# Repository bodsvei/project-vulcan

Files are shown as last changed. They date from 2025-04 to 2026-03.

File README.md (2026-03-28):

# Project VULCAN

vulcan

A humanoid robot facial structure that can interact with humans — tracking faces, expressing emotions, hearing and speaking.

---

## Features

- **Eyes** — Independent 2-axis eyeball motion, eyelids, and gaze tracking via embedded cameras
- **Mouth** — Lip movement synced with speech and emotional expressions
- **Eyebrows** — Up/down motion to complement expressions
- **Neck** — 2-axis motion (horizontal 360° + vertical tilt)
- **Hearing & Speech** — Microphone array for sound localisation, speech recognition, and TTS output
- **Vision** — Face detection, gaze estimation, emotion recognition (FER), hand-wave detection
- **LLM Integration** — RAG-augmented responses via GPT

---

## Subsystems

### Mechanical
- [Eye, eyelid & eyebrow subsystem](https://www.youtube.com/watch?v=uqxhR49N3ws) — asymmetric eyeball motion with cameras, blinking, and brow movement
- [Mouth subsystem](https://www.youtube.com/watch?v=Ke2lJfY4haM) — lip articulation for speech and emotion
- [Neck subsystem](https://www.youtube.com/watch?v=GJRW8hP-Jcs) — full pan and tilt

### Software
- **`software/vision/`** — face detection, gaze estimation (`t_gaze.py`), emotion recognition (`m_model.py`, `m_expression.py`), hand-wave detection
- **`software/speech/`** — speech-to-text, TTS, voice selection
- **`software/llm/`** — GPT interface and RAG pipeline for context-aware responses
- **`software/core/`** — main driver (`vulcan.py`, `vulcan2.py`) coordinating all subsystems

### Electronics
- Servo PCB (ESP32 & Mega variants) — custom KiCad boards in `electronics/pcb/`
- ESP32-CAM firmware — `electronics/firmware/camera_esp/`
- Arduino servo firmware — `electronics/firmware/serial_arduino/`

---

## Repository Structure

```
project-vulcan/
├── docs/                   # Install guides (CUDA, OpenCV, dlib), diagrams
├── software/
│   ├── core/               # Main entry points
│   ├── vision/             # CV modules
│   ├── speech/             # STT / TTS
│   ├── llm/                # GPT + RAG pipeline
│   │   └── rag/
│   ├── data/               # Knowledge base files for RAG
│   ├── utils/              # Shared helpers
│   ├── tools/              # Diagnostic scripts (check mic, list cameras)
│   ├── experiments/        # Prototypes and WIP scripts
│   ├── models/             # Model weights (gitignored — see models/README.md)
│   ├── archive/            # Deprecated code
│   └── requirements.txt
├── electronics/
│   ├── pcb/                # KiCad projects
│   ├── firmware/           # Arduino / ESP32 sketches
│   └── scripts/            # Python hardware-communication scripts
└── mechanical/             # CAD files (SolidWorks, Fusion, Blender, STL)
    ├── Eye_subsystem/
    ├── Mouth_Subsystem/
    ├── Head Structure/
    ├── Neck Base/
    └── base_holder/
```

> **Model weights** are not tracked in git — see [`software/models/README.md`](software/models/README.md) for download links.  
> **Install guides** for CUDA, OpenCV, and dlib are in [`docs/`](docs/).

---

## Getting Started

```bash
# Install Python dependencies
pip install -r software/requirements.txt

# Download model weights (see software/models/README.md), then run
python software/core/vulcan2.py
```

---

## Built With

- [Python](https://www.python.org/)
- [OpenCV](https://opencv.org/)
- [dlib](http://dlib.net/)
- [LangChain](https://www.langchain.com/) / [OpenAI](https://openai.com/)
- [KiCad](https://www.kicad.org/)
- [ROS](https://www.ros.org/)

## Limitations

- The robot covers only the structure above the neck — no full-body mobility.

## Papa

- [Parth Shah](https://github.com/Parth-Shah-Tool-Kit)
- [Ritwik Sharma](https://github.com/Maker-Rat)

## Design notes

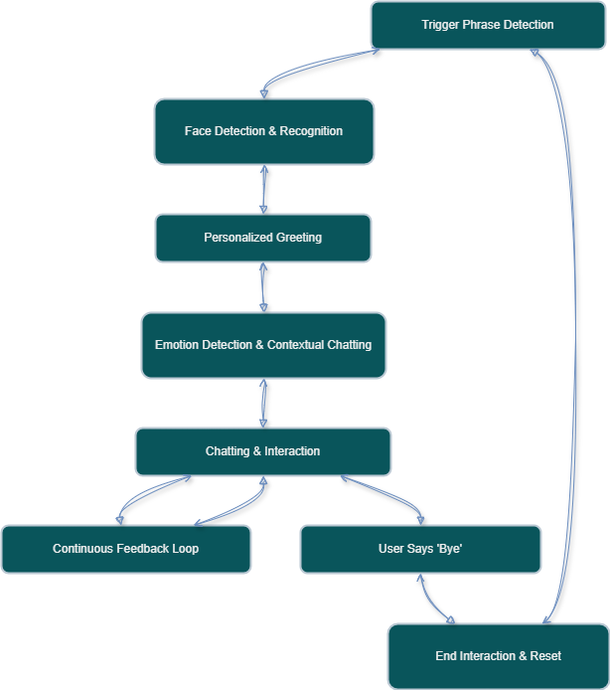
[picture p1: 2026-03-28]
docs/workflow.png

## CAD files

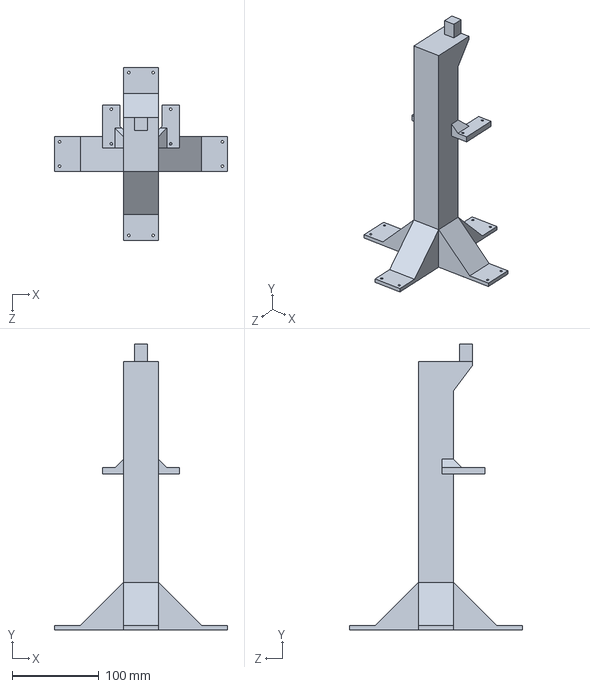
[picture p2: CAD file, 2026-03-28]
mechanical/base_holder/main.SLDPRT
200.0 x 330.0 x 200.0 mm

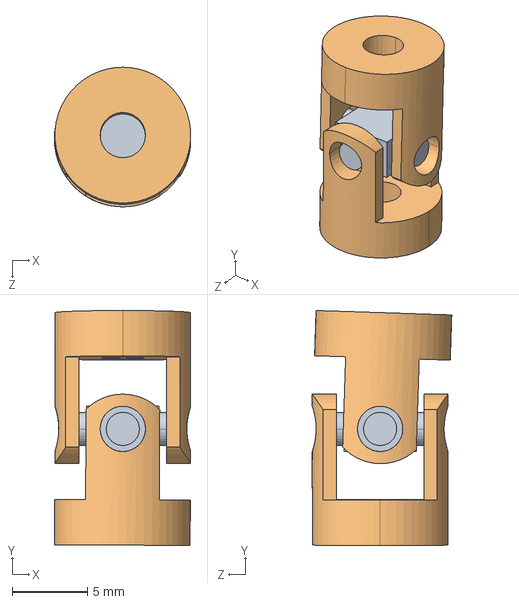
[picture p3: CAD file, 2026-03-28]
mechanical/Eye_subsystem/Solidworks/pla/UV/UV_Final.SLDASM
9.04 x 15.6 x 9.25 mm
UV cross spider[1].step
UV Yoke[1].step x 2

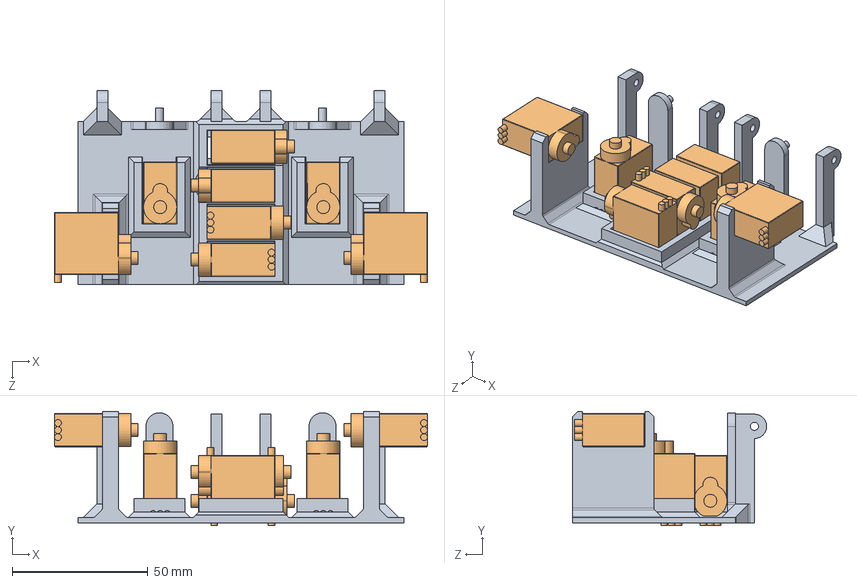
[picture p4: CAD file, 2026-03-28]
mechanical/Eye_subsystem/Solidworks/refrence/Eye Base Plate and Eyes/EyeAssembly.SLDASM
137.2 x 42.0 x 71.5 mm
BASE_v1_complete
servofinal x 8

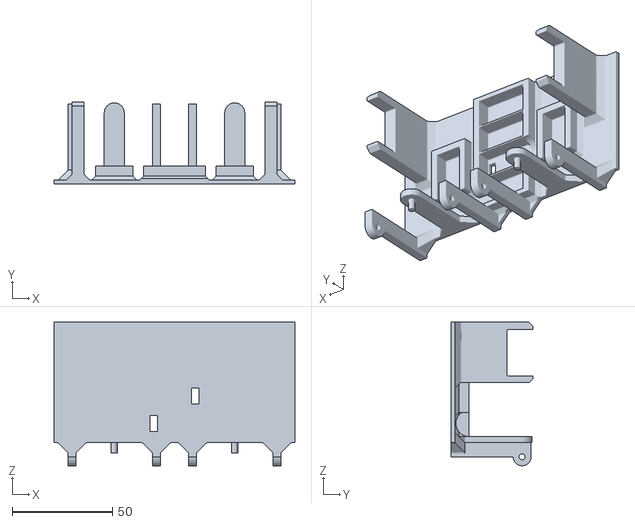
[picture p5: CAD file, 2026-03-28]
mechanical/Eye_subsystem/Solidworks/refrence/Eye Base Plate and Eyes/BASE_v1_complete.STL
120.0 x 41.0 x 71.5

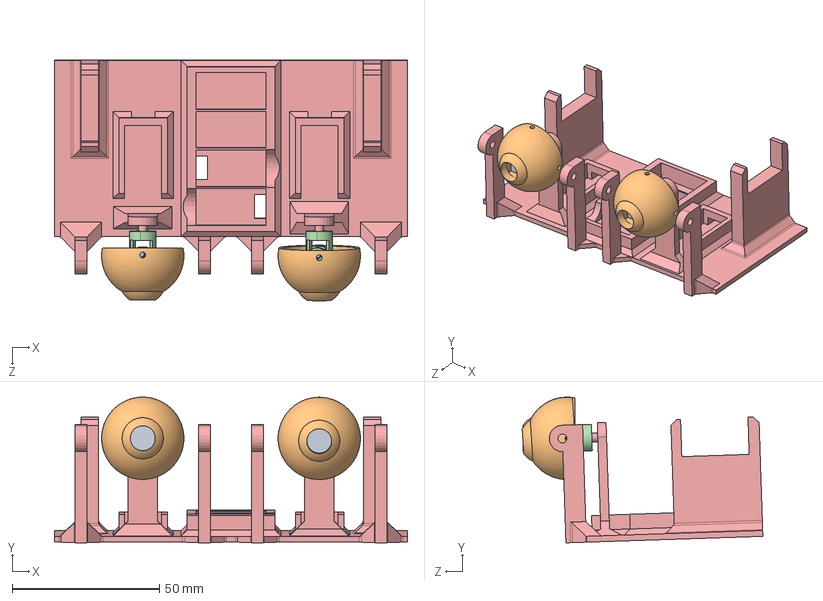
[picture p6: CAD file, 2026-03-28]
mechanical/Eye_subsystem/Solidworks/pla/EyeAssemblyFinal_StepppFile.SLDASM
120.0 x 49.5 x 81.9 mm
UVHOLDERSLDPART x 2
eye ball x 2
UV cross spider[1].step x 2
UV Yoke[1].step x 4
BASE_v3_pasha

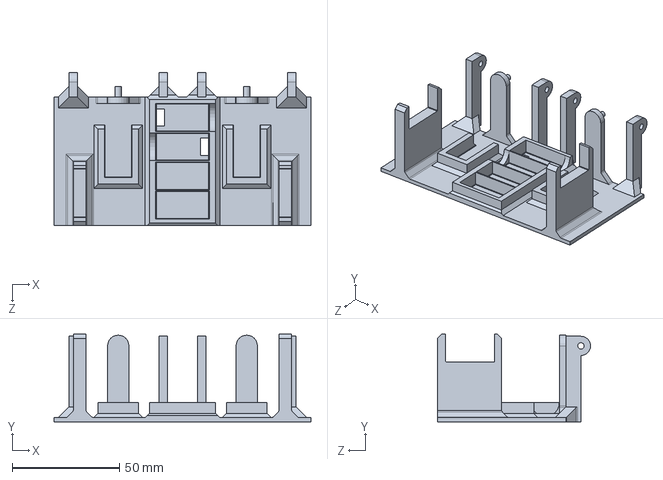
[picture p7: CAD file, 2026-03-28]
mechanical/Eye_subsystem/Solidworks/pla/BASE_v2_complete.SLDPRT
120.0 x 41.0 x 71.5 mm

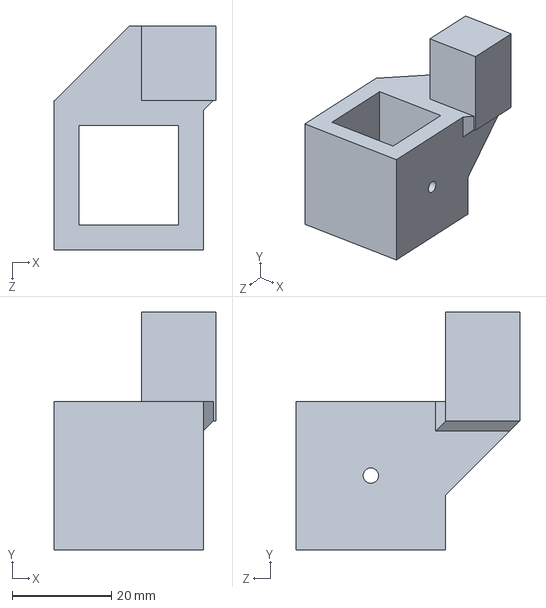
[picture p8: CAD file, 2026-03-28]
mechanical/base_holder/v2/top.SLDPRT
32.6 x 48.0 x 45.1 mm

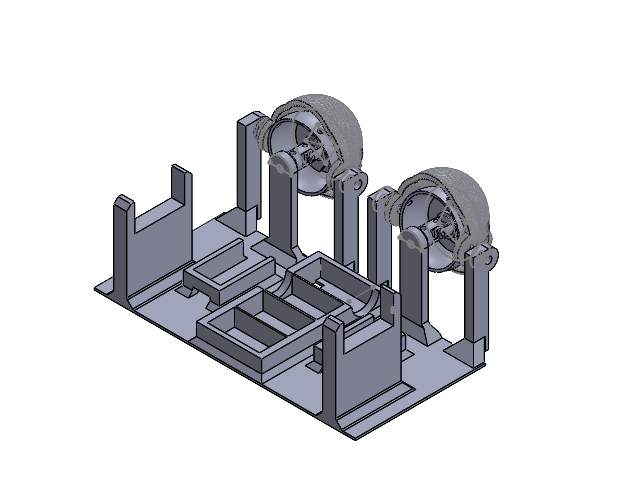
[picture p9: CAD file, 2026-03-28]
mechanical/Eye_subsystem/Solidworks/metal/EyeSubSystem_v5.SLDASM
BASE_v4_metal
Cross metal x 2
UV metal x 4
UVHOLDERSLDPART_v3 x 2
eye ball x 2
lower_eye_lid x 2
Upper Eye Lid x 2

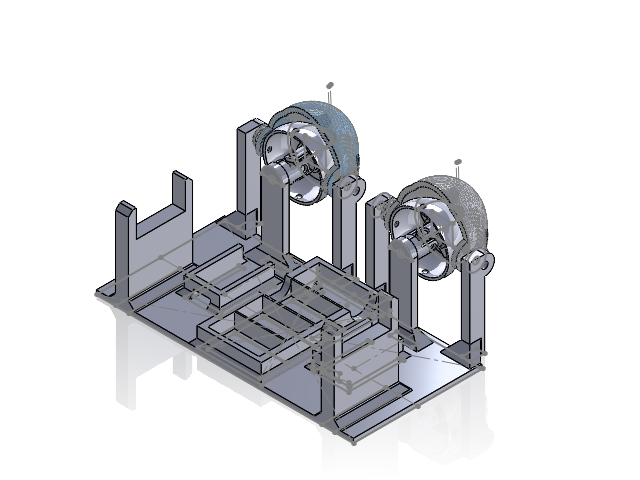
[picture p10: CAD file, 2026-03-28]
mechanical/Eye_subsystem/Solidworks/pla/EyeSubSystem.SLDASM
BASE_v3_pasha
UV cross spider[1].step x 2
UV Yoke[1].step x 4
UVHOLDERSLDPART x 2

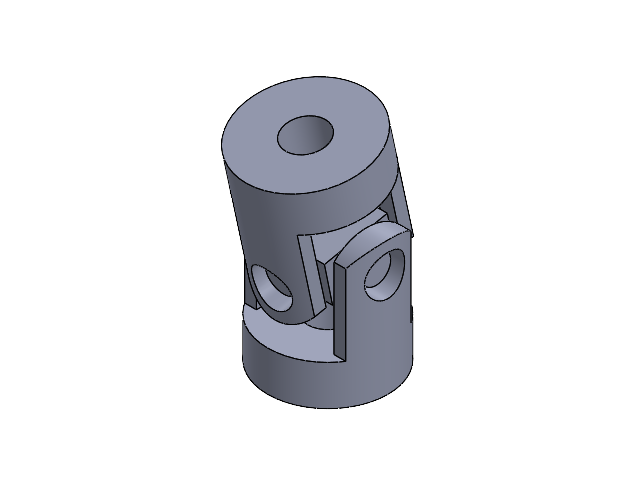
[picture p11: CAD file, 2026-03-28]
mechanical/Eye_subsystem/Solidworks/pla/UV/UV.SLDASM
UV Yoke x 2
UV cross spider

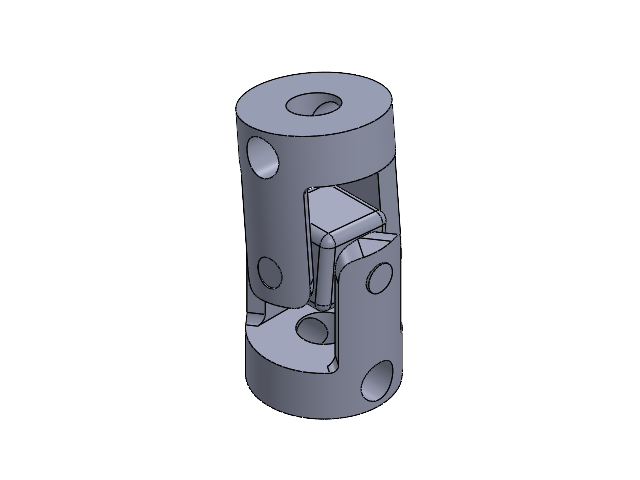
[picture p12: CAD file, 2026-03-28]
mechanical/Eye_subsystem/Solidworks/metal/UV_metal.SLDASM
Cross metal
UV metal x 2

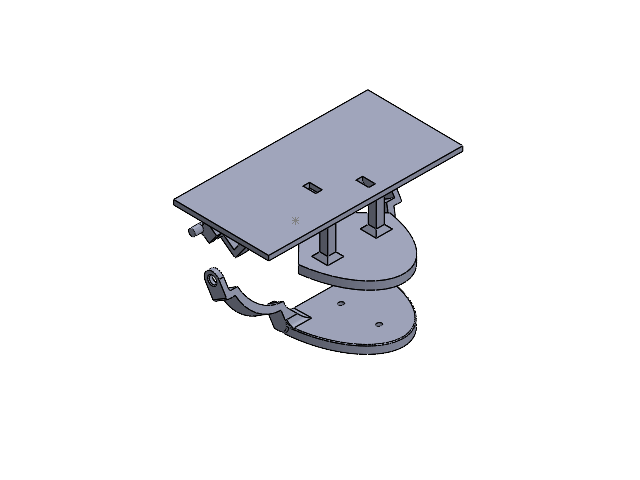
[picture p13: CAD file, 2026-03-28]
mechanical/Mouth_Subsystem/Solidworks/Full_Mechanism/MouthFinished.SLDASM
Lower_Jaw_Plate
Mouth_Base
Cap
servofinal[1] x 2
Slider_DriverServo
Sliding_servo
Connector

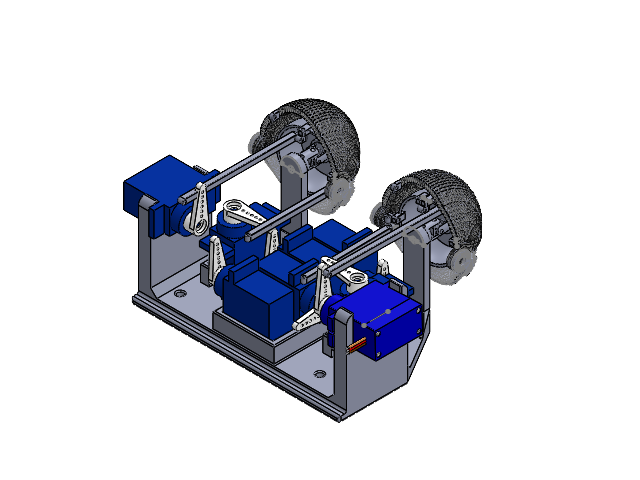
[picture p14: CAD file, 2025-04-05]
mechanical/Eye_subsystem/Solidworks/main/assem.SLDASM
BASE_v8
servofinal[1] x 7
servo_dandi x 8
pusher_rod x 2
pusher_rod_mini x 2
pusher_rod_lr x 2
pusher_rod_mini_lr x 2
Cross metal x 2
UV metal x 4
eye ball_for_pusher_rod x 3
UVHOLDERSLDPART_v3 x 2
Tower+Pro+9g+Micro+Servo+SG90
Upper_eyelid_for_push_rod x 2
Lower_eyelid_for_push_rod x 2

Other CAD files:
mechanical/Eye_subsystem/Solidworks/pla/EyeAssemblyFinal.SLDASM
mechanical/Eye_subsystem/Solidworks/main/UV_metal.SLDASM
mechanical/Eye_subsystem/Solidworks/pla/EyeAssemblyFinal2.SLDASM
mechanical/Eye_subsystem/Solidworks/pla/UV_Final.SLDASM
mechanical/Eye_subsystem/Blender/Eyeball.blend
mechanical/Eye_subsystem/Fusion/eyeball_blender_to_fusion.f3d
mechanical/Eye_subsystem/Fusion/eyeball_dimensionally_inorrect.f3d
mechanical/Eye_subsystem/Solidworks/main/BASE_v7.SLDPRT
mechanical/Eye_subsystem/Solidworks/main/BASE_v8.SLDPRT
mechanical/Eye_subsystem/Solidworks/main/Cross metal.SLDPRT
mechanical/Eye_subsystem/Solidworks/main/Lower_eyelid_for_push_rod.SLDPRT
mechanical/Eye_subsystem/Solidworks/main/Tower+Pro+9g+Micro+Servo+SG90.SLDPRT
mechanical/Eye_subsystem/Solidworks/main/UV metal.SLDPRT
mechanical/Eye_subsystem/Solidworks/main/UVHOLDERSLDPART_v3.SLDPRT
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

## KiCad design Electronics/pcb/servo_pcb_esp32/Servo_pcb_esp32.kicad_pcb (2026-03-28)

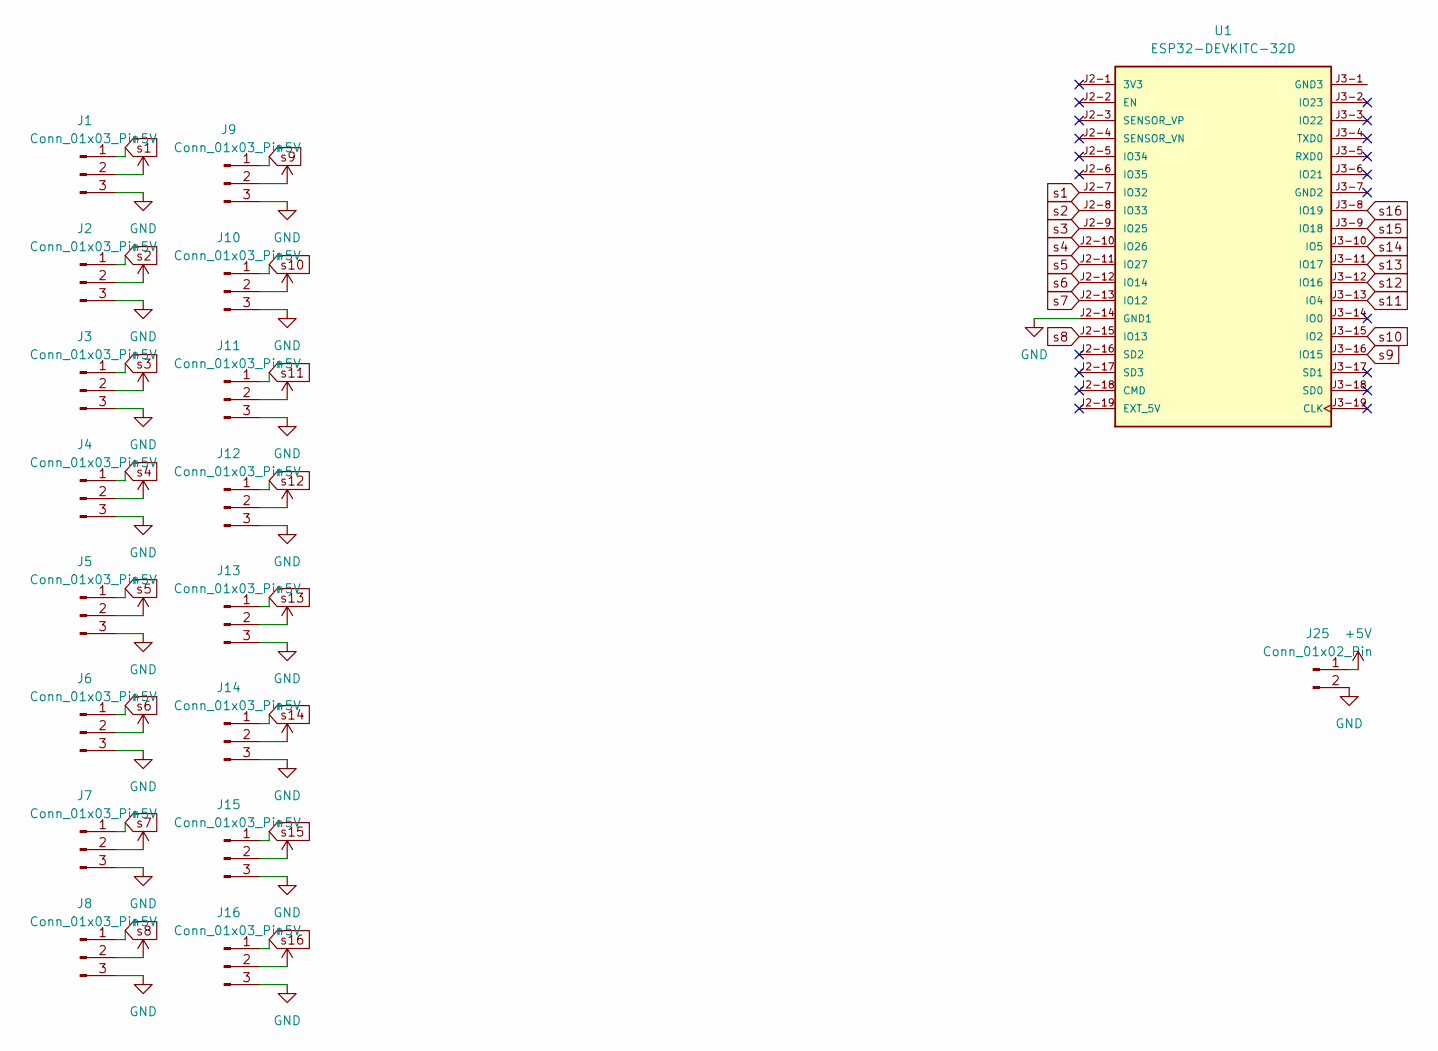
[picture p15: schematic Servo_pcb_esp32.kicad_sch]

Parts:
J1, J2, J3, J4, J5, J6, J7, J8, J9, J10, J11, J12, J13, J14, J15, J16: Conn_01x03_Pin; PinHeader_1x03_P2.54mm_Vertical
J25: Conn_01x02_Pin; AMASS_XT60-M_1x02_P7.20mm_Vertical
U1: ESP32-DEVKITC-32D; MODULE_ESP32-DEVKITC-32D; PARTREV V4

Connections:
+5V: J1.2, J2.2, J3.2, J4.2, J5.2, J6.2, J7.2, J8.2, J9.2, J10.2, J11.2, J12.2, J13.2, J14.2, J15.2, J16.2, J25.1
GND: J1.3, J2.3, J3.3, J4.3, J5.3, J6.3, J7.3, J8.3, J9.3, J10.3, J11.3, J12.3, J13.3, J14.3, J15.3, J16.3, J25.2, U1.J2-14 (GND1)
s1: J1.1, U1.J2-7 (IO32)
s2: J2.1, U1.J2-8 (IO33)
s3: J3.1, U1.J2-9 (IO25)
s4: J4.1, U1.J2-10 (IO26)
s5: J5.1, U1.J2-11 (IO27)
s6: J6.1, U1.J2-12 (IO14)
s7: J7.1, U1.J2-13 (IO12)
s8: J8.1, U1.J2-15 (IO13)
s9: J9.1, U1.J3-16 (IO15)
s10: J10.1, U1.J3-15 (IO2)
s11: J11.1, U1.J3-13 (IO4)
s12: J12.1, U1.J3-12 (IO16)
s13: J13.1, U1.J3-11 (IO17)
s14: J14.1, U1.J3-10 (IO5)
s15: J15.1, U1.J3-9 (IO18)
s16: J16.1, U1.J3-8 (IO19)

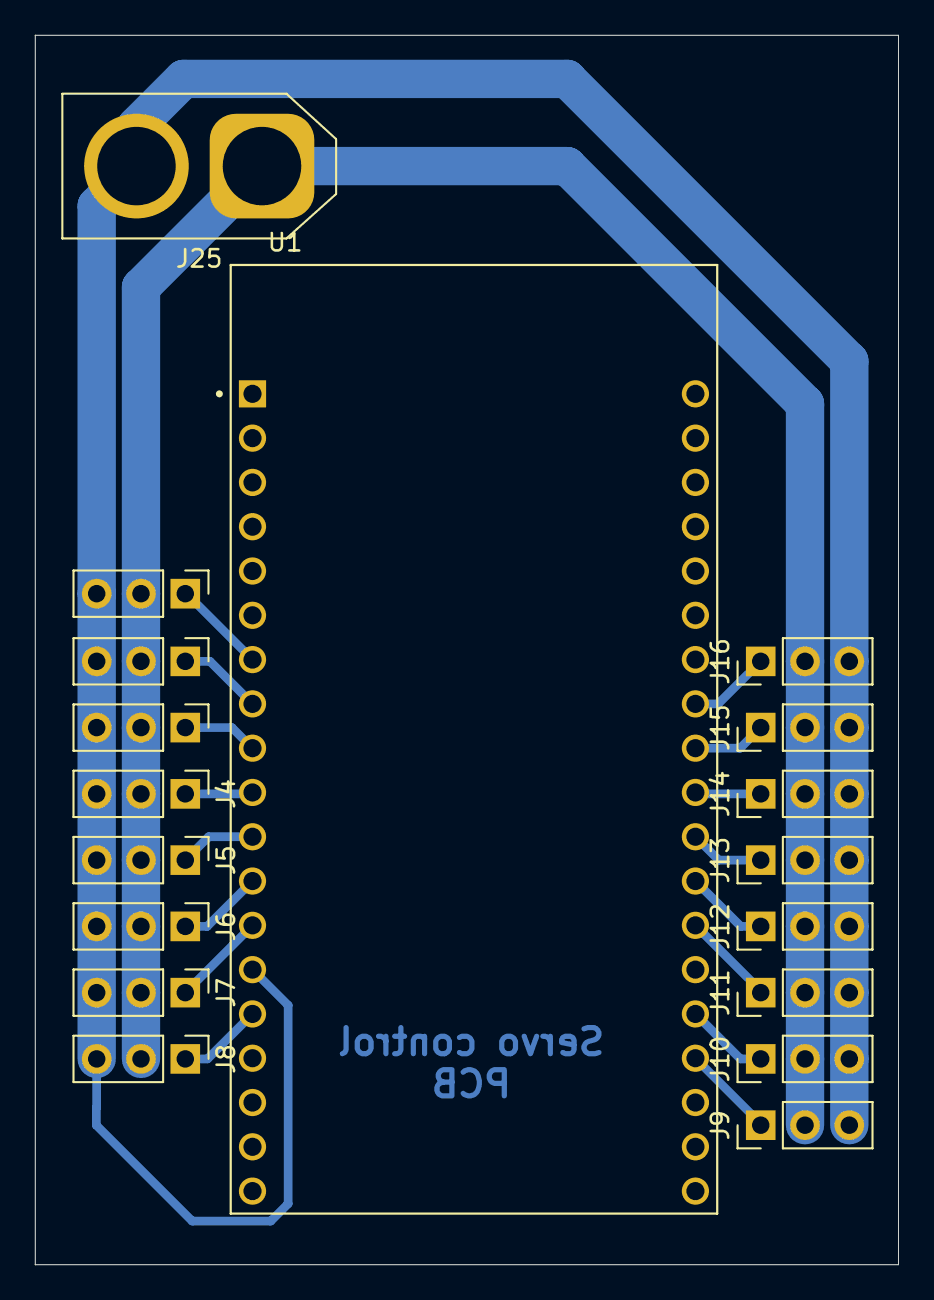
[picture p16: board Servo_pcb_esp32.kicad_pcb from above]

Board: 2 copper layers, 49.5 x 70.5 mm, 18 parts (0 on the bottom side), 18 nets.

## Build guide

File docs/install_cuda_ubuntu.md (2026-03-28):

How to install gpu support for linux. (i am using ubuntu 22, python 3.10, rtx 3050 4gb, intel i7 12g)

1. Take backup
2. Remove any relevant installs:

sudo bash -c "echo 'blacklist nouveau' > /etc/modprobe.d/blacklist-nouveau.conf"
sudo bash -c "echo 'options nouveau modeset=0' >> /etc/modprobe.d/blacklist-nouveau.conf"

sudo apt-get --purge remove "*nvidia*"
sudo apt-get --purge remove "*cuda*"
sudo apt-get --purge remove "*cublas*" "cuda*" "nsight*"
sudo apt-get autoremove
sudo apt-get autoclean

sudo update-initramfs -u

sudo reboot

3. Now install basic nvidia driver

sudo apt-get update
sudo apt-get install nvidia-driver-535 (535 is for rtx 3050 search your releveant one)

4. Fix broken packages: 
sudo apt-get install -f
sudo apt-mark showhold

5. find the cuda version for your gpu (12.2 for mine):
https://developer.nvidia.com/cuda-12-2-0-download-archive
follow the steps for deb(local) > best way

do everthing in the /home/user/ folder

6. Add Env varibles
echo $PATH
echo $LD_LIBRARY_PATH
echo 'export PATH=/usr/local/cuda-12.2/bin${PATH:+:${PATH}}' >> ~/.bashrc
echo 'export LD_LIBRARY_PATH=/usr/local/cuda-12.2/lib64${LD_LIBRARY_PATH:+:${LD_LIBRARY_PATH}}' >> ~/.bashrc

sudo reboot

7. Check if cuda is installed:
source ~/.bashrc
nvcc --version
something like:
nvcc: NVIDIA (R) Cuda compiler driver
Copyright (c) 2005-2023 NVIDIA Corporation
Built on Tue_Jun_13_19:16:58_PDT_2023
Cuda compilation tools, release 12.2, V12.2.91
Build cuda_12.2.r12.2/compiler.32965470_0

should come.

8. find the cudnn version for your cuda from here: (9.2 for mine)
https://docs.nvidia.com/deeplearning/cudnn/latest/reference/support-matrix.html
download cudnn from here:
https://developer.nvidia.com/cudnn-downloads

dpkg -l | grep cudnn
this should show atlest:
ii  cudnn9-cuda-12                                     9.2.0.82-1                                        amd64        NVIDIA cuDNN for CUDA 12

with ii in the start.

sudo reboot for cudnn installation if you get random errors.

sudo apt-get install libcudnn8
sudo apt-get install libcudnn8-dev

incase of package not found,

wget https://developer.download.nvidia.com/compute/cuda/repos/ubuntu2004/x86_64/cuda-ubuntu2004.pin
sudo mv cuda-ubuntu2004.pin /etc/apt/preferences.d/cuda-repository-pin-600
export last_public_key=3bf863cc # SEE NOTE BELOW
sudo apt-key adv --fetch-keys https://developer.download.nvidia.com/compute/cuda/repos/ubuntu2004/x86_64/${last_public_key}.pub
sudo add-apt-repository "deb https://developer.download.nvidia.com/compute/cuda/repos/ubuntu2004/x86_64/ /"
sudo apt-get update
sudo apt-get install libcudnn8
sudo apt-get install libcudnn8-dev

now if libcudnn gets installed, you are done with cudnn installation.

9. Install NVIDIA Video Codec SDK
from https://developer.nvidia.com/video-codec-sdk
refer https://www.youtube.com/watch?v=zap4k6LKnYA

9. Now we build opencv!

pip3 uninstall opencv-python

sudo apt-get update
sudo apt-get install build-essential cmake git libgtk2.0-dev pkg-config libavcodec-dev libavformat-dev libswscale-dev
sudo apt-get install libgstreamer-plugins-base1.0-dev libgstreamer1.0-dev libgl1-mesa-dev libglu1-mesa-dev
sudo apt-get install python3-dev python3-numpy libtbb2 libtbb-dev libjpeg-dev libpng-dev libtiff-dev libdc1394-22-dev

sudo apt-get install libdc1394-dev

git clone https://github.com/opencv/opencv.git
git clone https://github.com/opencv/opencv_contrib.git
cd opencv_contrib
git checkout <opencv_version>  # Replace <opencv_version> with the version you want to build (e.g., 4.5.5)
cd ..

cd opencv
git checkout <opencv_version>  # Replace <opencv_version> with the version you want to build (e.g., 4.5.5)
mkdir build
cd build

# Configure with CUDA and cuDNN support
cmake .. -DOPENCV_EXTRA_MODULES_PATH=../opencv_contrib/modules \
         -DWITH_CUDA=ON \
         -DCUDA_ARCH_BIN=8.6 \
         -DCUDA_FAST_MATH=ON \
         -DCUDNN_VERSION=9.6.0 \
         -DCUDNN_INCLUDE_DIR=/usr/include \
         -DCUDNN_LIBRARY=/usr/lib/libcudnn.so.9.6.0 \
         -DBUILD_opencv_python2=OFF \
         -DBUILD_opencv_python3=ON \
         -DPYTHON_DEFAULT_EXECUTABLE=/usr/bin/python3 \
         -DWITH_GSTREAMER=ON \
         -DWITH_LIBV4L=ON \
         -DENABLE_FAST_MATH=ON \
         -DCMAKE_BUILD_TYPE=RELEASE \
         -DBUILD_EXAMPLES=OFF \
         -DBUILD_TESTS=OFF \
         -DBUILD_PERF_TESTS=OFF

# Adjust options as per your specific requirements

make -j10 (replace 10 with no of your cpu cores) (this is for building)
sudo make install
sudo ldconfig

if you mess up, uninstall cudnn and do again.

if you get this error: 
"CMake Error at modules/dnn/CMakeLists.txt:53 (message):
  DNN: CUDA backend requires cuDNN.  Please resolve dependency or disable
  OPENCV_DNN_CUDA=OFF"
  
  It means cudnn install is improper/incomplete/not supported. So delete and install again (best)
  
To test for sucessful build:

python3
import cv2
print(cv2.__version__)
print(cv2.getBuildInformation())
cv2.cuda.getCudaEnabledDeviceCount()

last one should print 1

If you made it so far congratulations! its easy now.

sudo rm -rf ~/opencv
sudo rm -rf ~/opencv_contrib

10. Now we build dlib!

pip3 uninstall dlib

cd
git clone https://github.com/davisking/dlib.git
cd dlib
mkdir build
cd build
cmake .. -DDLIB_USE_CUDA=1 -DUSE_AVX_INSTRUCTIONS=1
cmake --build .
sudo make install
sudo ldconfig
cd ../
python3 setup.py install --set USE_AVX_INSTRUCTIONS=1 --set DLIB_USE_CUDA=1

incase of an error write
python3 setup.py install --set USE_AVX_INSTRUCTIONS=1 --set DLIB_USE_CUDA=1 --user
and retry

test with:
import dlib
print("Dlib version:", dlib.__version__)
print("CUDA support:", dlib.DLIB_USE_CUDA)

sudo rm -rf ~/dlib

11. Now we build tensorflow!

pip3 uninstall tensorflow
python3 -m pip install tensorflow[and-cuda]

to test:
import tensorflow as tf

# Check if TensorFlow can access GPU
print("Num GPUs Available:", len(tf.config.experimental.list_physical_devices('GPU')))

12. Now we build pytorch!

pip3 uninstall torch torchvision torchaudio
rm -rf ~/.cache/torch
pip3 list | grep torch

this should be empty

pip3 install torch torchvision torchaudio -f https://download.pytorch.org/whl/cu12.2/torch_stable.html

this is for cuda 12.2 choose link accordingly

to test:
import torch
print(torch.__version__)
print(torch.cuda.is_available())

if you get "ImportError: libcudnn.so.8: cannot open shared object file: No such file or directory"
while doing import torch
then do:

sudo rm /usr/lib/x86_64-linux-gnu/libcudnn.so.8
sudo ln -s /usr/lib/x86_64-linux-gnu/libcudnn.so.9.2.0 /usr/lib/x86_64-linux-gnu/libcudnn.so.8

/usr/lib/x86_64-linux-gnu is the place where your libcudnn should be present

sudo apt-cache policy libcudnn8
and then install the appropriate version.

If you make it so far, congratulations. Your done!

GG. 
Happy computer vision at good fps.

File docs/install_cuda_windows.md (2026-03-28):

Cuda version: 11.2 download from nvidia website.
download zlib and add .dll to path
CUDNN v 8.1.1.33 download from nvidia website. follow installation instructions from website.
dont forget to add cudnn to path.
check by typing nvcc --version in cmd.

dlib download 19.23 from github
opencv 4.x from github.
opencv_contrib same v from github.

download cmake as a software, not with pip
download visual studio 2019.
install visual studio build tools 2017 and 2019. select c++ tools. make sure tools for cmake is ticked.

now we build dlib.
use cmake to build dlib.

use source code as dlib folder path
where to build as dlib folder path / build. create a build folder by yourself.

Make sure you dont use jionet now onwards.
If you see blank screen, press configure. use visual studio 2017 and set x64 in next blank.
now change DLIB_USE_CUDA to ON or ticked and same for DLIB_LINK_WITH_SQLITE3.

now press configure and if you see "DLIB WILL USE CUDA", congrats, you are almost done (hopefully). Delete older installed versions of dlib with pip or go into site_packages folder and delete it.
Now press generate and close cmake once this is done.
Go to build folder that you create. open cmd there and type "cmake ." . after this do cd.. or go to dlib folder and open cmd. type "python setup.py install"

you can check by closing all python codes and opening a python terminal and writing in shell:

import dlib
dlib.DLIB_USE_CUDA
if you get true, congratulations.

moving to open cv, first uninstall all.
https://www.youtube.com/watch?v=d8Jx6zO1yw0
follow this video step by step.

hope it works.

I have used python 3.7.4, windows 11, nvidia gpu rtx 3050, intel i7 (x64).

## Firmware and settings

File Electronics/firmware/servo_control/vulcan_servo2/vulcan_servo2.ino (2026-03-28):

#include <ESP32Servo.h>

// Define the servo object
Servo Mouth_linear;
Servo Mouth_Rotational;
//Servo myServo3;
//Servo myServo4;
Servo L_lid_D;
Servo L_lid_U;
Servo L_eye_LR;
Servo L_eye_UD;
Servo R_eye_UD;
Servo R_eye_LR;
Servo R_lid_U;
Servo R_lid_D;
//Servo myServo13;
//Servo myServo14;
//Servo myServo15;
//Servo myServo16;

bool blinking = 1;
bool Talk = 0;

hw_timer_t *timer1 = NULL;
hw_timer_t *timer2 = NULL;

int L_eye_H = 87;
int L_eye_V = 97;
int R_eye_H = 125;
int R_eye_V = 80;

int increment = 4;

volatile int angle_2 = 0;
volatile bool increasing2 = true;

volatile int angle3 = 0;
volatile bool increasing3 = true;

int blink_speed = 2;
int talking_speed = 2;
int bl_counter = 0;
int tl_counter = 0;

int randomNumber = random(5, 10);

void IRAM_ATTR onTimer1() 
{
  tl_counter++;
  if(blinking==1)
  {
    if(bl_counter%(randomNumber*1000) == 0)
    {
      L_lid_U.write(70);
      R_lid_U.write(40);
    }
    if(bl_counter%(randomNumber*1000) == 250)
    {
      L_lid_U.write(0);
      R_lid_U.write(135);
      randomNumber = random(3, 7);
      blinking = 0;
    }
    bl_counter++;
  }
  if(Talk==1)
  {
    if(tl_counter% 800 == 0)
    {
      Mouth_Rotational.write(95);
    }
    if(tl_counter%800 == 400)
    {
      Mouth_Rotational.write(85);
    }
  }
}


void setup() {
  Serial.begin(115200);

  Mouth_linear.attach(15);
  Mouth_Rotational.attach(2);
  //  myServo3.attach(4);
  //  myServo4.attach(16);
  L_lid_D.attach(17);
  L_lid_U.attach(5);
  L_eye_LR.attach(18);
  L_eye_UD.attach(19);
  R_eye_UD.attach(32);
  R_eye_LR.attach(33);
  R_lid_U.attach(25);
  R_lid_D.attach(26);
  //  myServo13.attach(27);
  //  myServo14.attach(14);
  //  myServo15.attach(12);
  //  myServo16.attach(13);
  
  L_lid_D.write(85);
  L_lid_U.write(0);
  L_eye_LR.write(87);
  L_eye_UD.write(97);
  R_eye_UD.write(80);
  R_eye_LR.write(125);
  R_lid_U.write(135);
  R_lid_D.write(117);
  Mouth_linear.write(140);
  Mouth_Rotational.write(85);

    // Create a hardware timer
  timer1 = timerBegin(1000000); // Timer 1, prescaler of 80 (1 tick = 1 µs)
  timerAttachInterrupt(timer1, &onTimer1); // Attach interrupt
  timerAlarm(timer1, 1000, true, 0); // Set alarm to 5 seconds (5,000,000 µs)

//  timer2 = timerBegin(1000000); // Timer 2
//  timerAttachInterrupt(timer2, &onTimer2);
//  timerAlarm(timer2, 1000, true, 0); // 300 miliseconds for Servo 2
}

void check_cond()
{
   if (L_eye_V >= 115)
      L_eye_V = 115;
    if (L_eye_V <= 85)
      L_eye_V = 85;
      
    if (L_eye_H >= 115)
      L_eye_H = 115;
    if (L_eye_H <= 60)
      L_eye_H = 60;

    if (R_eye_V >= 100)
      R_eye_V = 100;
    if (R_eye_V <= 65)
      R_eye_V = 65;
      
    if (R_eye_H >= 150)
      R_eye_H = 150; 
    if (R_eye_H <= 95)
      R_eye_H = 95;
}
void loop() {
  unsigned long currentMillis = millis();  // Get the current time

  if (Serial.available() > 0) 
  {
    int receivedValue = 5;
    receivedValue = Serial.parseInt();
    Serial.println(receivedValue);
   
    if (receivedValue == 1)             //Eye left
    {
      L_eye_H += increment;
      R_eye_H += increment;
    } 
    else if (receivedValue == 2)        //Eye right
    {
      L_eye_H -= increment;
      R_eye_H -= increment;
    } 
    else if (receivedValue == 3)        //Eye up 
    {
      L_eye_V += increment;
      R_eye_V -= increment;
    } 
    else if (receivedValue == 4)        //Eye down 
    {
      
      L_eye_V -= increment;
      R_eye_V += increment;
    } 
    else if (receivedValue == 5)        //Centre 
    {
      L_eye_H = 87;
      L_eye_V = 97;
      R_eye_H = 125;
      R_eye_V = 80;
    } 
    else if (receivedValue == 6)        //Left wink
    {  
       blinking = 0;
       for (int angle = 0; angle <= 70; angle++) 
       {
          L_lid_U.write(angle);
          delay(10);
       }
       delay(500);
       L_lid_U.write(0);
       blinking = 1;
    } 
    else if (receivedValue == 7)        //Right wink
    {
      blinking = 0;
      for (int angle = 135; angle >= 40; angle--) 
      {
        R_lid_U.write(angle);
        delay(10);
      }
      delay(500);
      R_lid_U.write(135);
      blinking = 1;
    } 
    else if (receivedValue == 8)      //Talk
    {
      Talk = 1;
    } 
    else if (receivedValue == 9)      //Stop talk
    {
      Talk = 0;
    } 
    else if (receivedValue == 10)     //Yawn
    {
      if(Talk == 0)
      {
         blinking = 0;
        for (int angle = 85; angle <= 115; angle++) 
        {
            R_lid_U.write((int)(-3.167*angle+404.167));
           L_lid_U.write((int)(2.333*angle-198.333));
            Mouth_linear.write((int)(-1.433*angle+261.833));
            Mouth_Rotational.write(angle);
            delay(30);
        }
        delay(800);
        for (int angle = 115; angle >= 85; angle--) 
        {
            Mouth_linear.write((int)(-1.433*angle+261.833));
            Mouth_Rotational.write(angle);
            delay(5);
        }  
        L_lid_U.write(0);
        R_lid_U.write(135);
        blinking = 1;

      }
    } 
    else if (receivedValue == 11)     //Look around
    {
      // for (int angle = 125; angle <= 160; angle++)
      // {
      //   R_eye_LR.write(angle);
      //   L_eye_LR.write(3*angle-325);
      //   delay(30);
      // }
      // for (int angle = 160; angle >= 85; angle--) 
      // {
      //   R_eye_LR.write(angle);
      //   L_eye_LR.write(3*angle-325);
      //   delay(30);
      // }

      // for (int angle = 125; angle <= 150; angle++)
      // {
      //   R_eye_LR.write(angle);
      //   L_eye_LR.write(3*angle-325);
      //   delay(15);
      // }
      // for (int angle = 140; angle >= 85; angle--) 
      // {
      //   R_eye_LR.write(angle);
      //   L_eye_LR.write(3*angle-325);
      //   delay(15);
      // }
      
    } 
    else if (receivedValue == 12) 
    {
      //Eye roll
      /*for (int i = 0; i < steps; i++) 
      {
        // Calculate the angle in radians
        angle = (2 * PI / steps) * i;

        // Calculate x and y using parametric equations
        int x = xc + radius * cos(angle);
        int y = yc + radius * sin(angle);

        // Ensure x and y are within the allowed range
        if (x >= 70 && x <= 105 && y >= 86 && y <= 108) {
            printf("(%d, %d)\n", x, y);
        }
      }*/
    } else if (receivedValue == 13) {
      //Sleep
    } else if (receivedValue == 14) {
      //Squint
    } else if (receivedValue == 15) {
      //Creep eyes
    }
  }
    check_cond();
   
    if(blinking == 0)
    {
      L_lid_D.write(85);
      L_lid_U.write(0);
      R_lid_U.write(135);
      R_lid_D.write(117);
      blinking = 1;
    }
    L_eye_LR.write(L_eye_H);
    L_eye_UD.write(L_eye_V);
    R_eye_UD.write(R_eye_V);
    R_eye_LR.write(R_eye_H);
    
    if(Talk == 0)
    {
      Mouth_linear.write(140);
      Mouth_Rotational.write(85);
    }

}

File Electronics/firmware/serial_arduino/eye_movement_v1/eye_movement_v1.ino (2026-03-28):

#include <Servo.h>

//CW -> towards zero (looking at servo)


Servo eye_left_right;
Servo eye_up_down;

Servo eyelid_up;
Servo myservo3;
Servo myservo4;
// Servo myservo5;
// Servo myservo6;
// Servo myservo7;
Servo eye_other;

int eye_left_right_angle = 90;
int eye_up_down_angle = 90;

int eyelid_up_angle = 30;
int eye_other_angle = 50;

int limit = 20, increment = 5;

int eye_change = 15;




unsigned long previousMillis = 0;     // Store the last time the servo moved
const unsigned long interval = 5000;  // 5 seconds in milliseconds
const unsigned long interval_blink = 100;


void setup() {
  // put your setup code here, to run once:
  Serial.begin(115200);

  eye_left_right.attach(2);
  eye_up_down.attach(3);

  eyelid_up.attach(4);
  //myservo4.attach(5);
  // myservo5.attach(6);
  // myservo6.attach(7);
  // myservo7.attach(8);
  // myservo8.attach(9);

  eye_left_right.write(90);
  eye_up_down.write(90);
  eyelid_up.write(eyelid_up_angle);

  eye_other.attach(5);
  eye_other.write(eye_other_angle);
}

void loop() {

  unsigned long currentMillis = millis();  // Get the current time

  if (Serial.available() > 0) {


    // Serial.println(Serial.parseInt());
    int receivedValue = 5;
    receivedValue = (int)Serial.read();
    Serial.println(receivedValue);


    if (receivedValue == 7) {
      //go left
      eye_left_right_angle += increment;

    } else if (receivedValue == 2) {
      //go right
      eye_left_right_angle -= increment;

    } else if (receivedValue == 1) {
      //go up
      eye_up_down_angle += increment;
    } else if (receivedValue == 3) {
      //go down
      eye_up_down_angle -= increment;
    } else if (receivedValue == 5) {
      //center
    }

    if (eye_left_right_angle >= 90 + limit)
      eye_left_right_angle -= increment;
    if (eye_left_right_angle <= 90 - limit)
      eye_left_right_angle += increment;

    if (eye_up_down_angle >= 90 + limit)
      eye_up_down_angle -= increment;
    if (eye_up_down_angle <= 90 - limit)
      eye_up_down_angle += increment;

    // Serial.println(eye_left_right_angle);
    eye_left_right.write(eye_left_right_angle);
    eye_up_down.write(eye_up_down_angle);
  }



  if (currentMillis - previousMillis >= interval) {
    // It's time to move the servo
    previousMillis = currentMillis;  // Save the last time the servo moved


    eyelid_up.write(eyelid_up_angle - eye_change);
    eye_other.write(eye_other_angle + eye_change);
    // eye_change = -eye_change;
    // delay(interval_blink);
    eyelid_up.write(eyelid_up_angle + eye_change);
     eye_other.write(eye_other_angle - eye_change);

    delay(interval_blink);
    eyelid_up.write(eyelid_up_angle - eye_change);
    eye_other.write(eye_other_angle + eye_change);


  }
}

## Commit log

2025-03-23 Face Mold 0.3mm STL and Blend Files added
    [Face_30um.blend, Model V5 Full Face with EyeLids.blend, assem.SLDASM]
2025-04-05 New face stuff
    [Lower_Jaw_Plate.STL, UV_metal.SLDASM, assem.SLDASM]
2025-04-06 New Face Files
    [LowerJaw_Attached.stl, Lower_EYELID.blend, Lower_Jaw_Plate.STL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]
2025-04-06 Changes to New Skull Files
    [New_Skin_Skull_Size_CorrectingV1_Dome.stl, New_Skin_Skull_Size_CorrectingV1_Jaw.stl]
2026-03-28 Changing repo structure
    [BASE.SLDPRT, BASE_v1_complete.SLDPRT, BASE_v1_complete.STL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]
2026-03-28 Delecting old files
    [BASE.SLDPRT, BASE_v1_complete.SLDPRT, BASE_v1_complete.STL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]
